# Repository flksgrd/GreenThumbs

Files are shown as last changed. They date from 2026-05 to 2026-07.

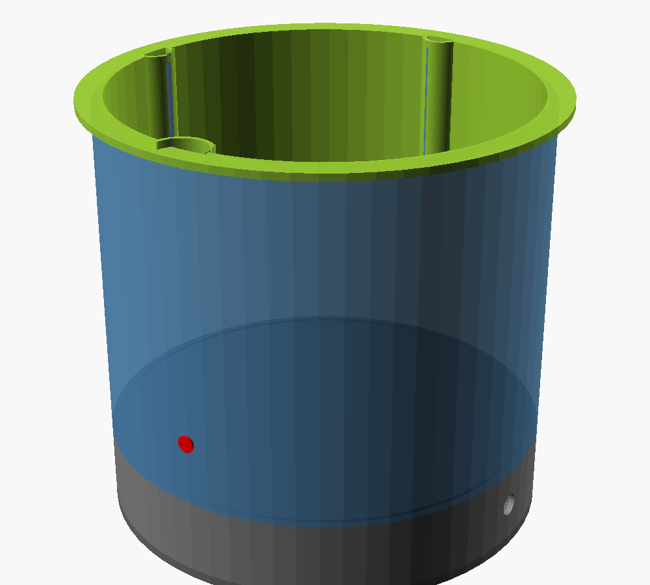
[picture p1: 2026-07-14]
pot/cad/preview/07-custom-monstera-iso.png

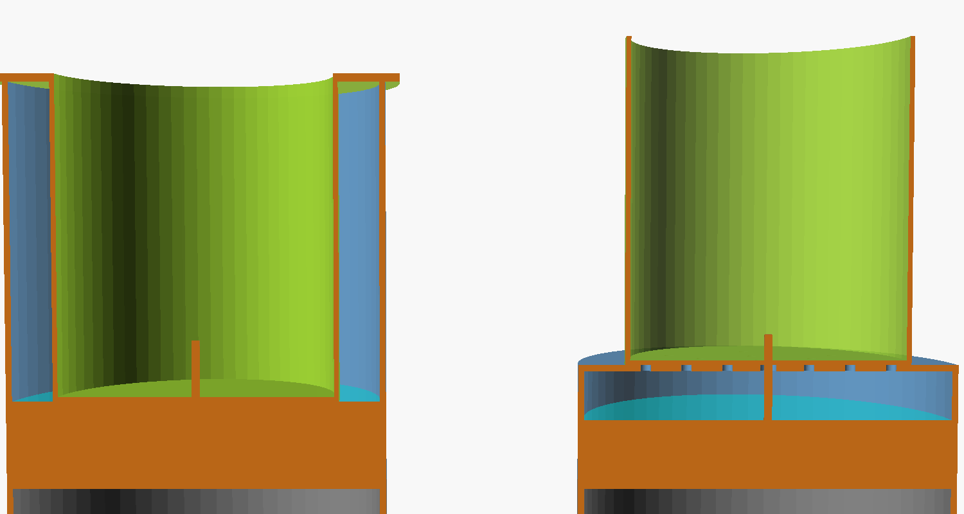
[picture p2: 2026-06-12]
pot/cad/preview/stack-variants-AB.png

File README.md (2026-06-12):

# 🌱 GreenThumbs

DIY auto-vandings-system til hjemmeplanter med Apple HomeKit-integration via Matter over Thread.

## Status

| Komponent | Status | Note |
|---|---|---|
| **v1: Smart Plantekrukke** | 🟡 Planlægning færdig, bygges nu | Modulær 3D-printet selvvandende krukke (med valgfri wick til bottom-watering) |
| **v2a: Pot-Orchid** | ⚪ Designfase only | Dedikeret orkide-krukke med soak-tray |
| **v2b: Vægmonteret Tower** | ⚪ Designfase only | Hydroponic til krydderurter/leafy greens |

## Oversigt

To designs til forskellige behov:

### 🪴 Smart Plantekrukke (v1 — denne iteration)

En modulær 3D-printet krukke der lever inde i en pyntepotte:

- **Plug-and-play planteprofiler**: Monstera, Pothos, Peace Lily, African Violet, Succulent, Orkide
- **Modulær sensor-stack**: kapacitiv jord-fugtighed + vandstand + float-switch + AHT20 (temp + RH) som basis. **Optional**: HX711 + 5kg load cell tilføjer vægt-detektion (krævet for orkide-bark; ikke nødvendigt for jord-planter)
- **VPD-aware vanding**: AHT20 measurer rum-klima og firmware skalerer dose dynamisk baseret på Vapor Pressure Deficit — mere vand i tør radiator-vinter, mindre i fugtigt klima
- **Bottom-watering option (v1 wick)**: bomulds-snor gennem center-drænhul → continuous capillary watering for African Violet, Peace Lily, Calathea og lignende fugt-elskere
- **Stille peristaltisk pumpe**: præcis dosering 5–100 ml, selv-primende, dry-run tolerant
- **Modulær størrelse**: skiftelig plantebeholder (S/M/L) — én reservoir + elektronik-base passer alle
- **Apple HomeKit** via Matter over Thread fra dag 1 (HomePod/Apple TV som Thread Border Router)
- **Strøm**: USB-C kablet i v1. Batteri-feasibility analyseret — realistisk i v2 med 3S 18650 + Sleepy End Device (~5-6 mdrs runtime)

→ Se [pot/](pot/) for byggeguide, hardware, firmware og CAD.

### 🪻 Pot-Orchid med Soak-Tray (v2a — kun planlægning)

Dedikeret orkide-krukke der mimicker manuel orkide-soaking: tray omkring plant cup oversvømmes via pump i 10-15 min, drænes derefter via solenoid eller passiv overflow tilbage til reservoir. Genbruger v1-elektronik 100%.

→ Se [pot-orchid/design-notes.md](pot-orchid/design-notes.md) for løbende planlægning.

### 🌿 Vægmonteret Hydroponic Tower (v2b — kun planlægning)

Vægophængt tower til krydderurter (basilikum, mynte, persille, koriander) og leafy greens (salat, spinat).
Deler MCU + firmware-platform med plantekrukken.

→ Se [tower/design-notes.md](tower/design-notes.md) for løbende planlægning.

## Quick reference

- **Komponentliste / BOM**: [pot/hardware/bom.csv](pot/hardware/bom.csv)
- **Wiring-diagram**: [pot/hardware/breadboard/wiring-diagram.md](pot/hardware/breadboard/wiring-diagram.md)
- **Planteprofiler**: [docs/plant-profiles.md](docs/plant-profiles.md)
- **Arkitektur**: [docs/architecture.md](docs/architecture.md)
- **Designbeslutninger (ADR)**: [docs/decisions/](docs/decisions/)
- **Research-noter**: [docs/research/](docs/research/) (KiCad rund PCB, piezo-komponenter)
- **Kalibrering**: [docs/calibration.md](docs/calibration.md)

## Tech stack

- **MCU**: Seeed Studio XIAO ESP32-C6 (Thread + WiFi + BLE + Matter)
- **Firmware**: PlatformIO + ESP-IDF + ESP-Matter SDK (C/C++)
- **CAD**: OpenSCAD (parametrisk, git-friendly)
- **3D print**: PETG til vand-kontakt dele, Prusa XL
- **Smart home**: Matter over Thread → Apple HomeKit

## Roadmap

- [x] Plan + arkitektur + BOM
- [ ] Bestil komponenter (AliExpress leadtime ~2-3 uger)
- [ ] Fase 1: Firmware bring-up på breadboard
- [ ] Fase 2: Mekanisk prototype i PLA → PETG
- [ ] Fase 3: Integration + 7-dages live-test
- [ ] Fase 4: Polish + assembly guide + OTA
- [ ] Fase 5: v2 tower-planlægning detaljeret

## License

MIT (software) — se [LICENSE](LICENSE). Hardware-design under overvejelse (CERN-OHL-S).

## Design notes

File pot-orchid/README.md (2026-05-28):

# 🪻 Pot-Orchid — Dedikeret orkide-krukke med soak-tray (v2)

**Status:** Designfase — bygges IKKE i denne iteration. Planlægges parallelt med v1 og vil bygge oven på lessons learned.

Dedikeret variant af plantekrukken designet specifikt til **orkider** (primært Phalaenopsis i bark-medium) og potentielt **store succulenter** der har gavn af ægte soak-watering.

## Hvorfor en separat krukke

Standard `pot/` v1 bruger top-drip via peristaltisk pumpe + drip-ring. Det virker godt for jord-baserede planter, men:

- **Orkide i bark**: bark-medium suger vand bedst ved nedsænkning (10-15 min soak), ikke drip. v1 approksimerer via 3×10s drip-bursts, men det er ikke ægte soaking.
- **Succulenter med tæt rosette** (Echeveria, Sempervivum, kaktus): top-drip kan ramme rosette-centrum → kronrådne. Bottom-watering via soak er sikrere.

Wick-løsningen i v1 dækker fugt-elskere (Peace Lily, African Violet, Calathea) men ikke orkide/succulent — disse vil have **tørre perioder** mellem soak-events, ikke konstant fugt.

→ Se [ADR 006](../docs/decisions/006-bottom-watering-strategies.md) for fuld kontekst.

## Quick reference (udfyldes løbende)

- [design-notes.md](design-notes.md) — løbende design-noter
- [references.md](references.md) — orkide-pleje litteratur, eksisterende designs
- preliminary-bom.md — kommer efter v1-validering

## Concept

```
┌──────────────────────────────┐
│  Lid med refill-tragt        │
├──────────────────────────────┤
│  INNER PLANT CUP             │  ← bark-medium, ikke jord
│   • Større drænhuller        │
│   • Soaker fra bunden via    │
│     tray-overflow            │
├──────────────────────────────┤
│  SOAK TRAY                   │  ← KEY DIFFERENCE
│   • Fyldes via pump (10-15min│
│     med vand op til soak-line│
│   • Drænes via solenoid eller│
│     passiv overflow tilbage  │
│     til reservoir            │
├──────────────────────────────┤
│  RESERVOIR                   │
├──────────────────────────────┤
│  ELECTRONICS BASE            │
│   • + solenoid driver         │
│   • + drain-control logik    │
└──────────────────────────────┘
```

## Forskelle fra pot/ v1

| Aspekt | pot/ v1 | pot-orchid/ v2 |
|---|---|---|
| Vandingsstrategi | Top-drip via drip-ring | Bottom-soak via tray |
| Pumpe-cyklus | Diskret dose 5-100ml | Fyld tray over 5-10 min |
| Drain-mekanisme | Ingen (cup-drænhuller → reservoir) | Solenoid eller passiv overflow |
| Medium | Jord | Bark (default) eller specialiseret kaktusjord |
| Soil-sensor | Capacitiv (relevant) | Måske irrelevant — vægt + tray-vandstand bruges |
| Tray-vandstand sensor | Ikke nødvendig | Ja (extra capacitive eller float) |
| Cup-design | Drænhuller spredt | Stort centralt drænhul + perimeter for tray-tilstrømning |

## Roadmap

- [ ] v1 (pot/) firmware + hardware fungerer end-to-end
- [ ] v1 wick-test: er bottom-watering tilstrækkeligt for fugt-elskere? Bekræfter behov for soak-tray til orkide/succulenter
- [ ] Udfyld design-notes med valg: solenoid-drain vs passiv overflow
- [ ] Beslut: udvider vi til 2 sizes (orkide small + stor succulent)?
- [ ] Skitse soak_tray.scad
- [ ] Foreløbig BOM (genbrug pot/-komponenter)
- [ ] Print + samling
- [ ] Live test med Phalaenopsis

## Genbrug fra pot/

| Komponent | Genbrug | Note |
|---|---|---|
| XIAO ESP32-C6 + ESP-Matter setup | 100% | Samme MCU + firmware base |
| Peristaltisk pumpe + MOSFET | 100% | Samme driver, anden brug (tray-fyld i stedet for drip) |
| HX711 + 5kg load cell | 100% | Vægt-baseret detektion er endnu vigtigere her |
| Float switch + interlock | 100% | Lavt vand i reservoir |
| ZY12PDN + MP1584 strøm | 100% | Samme |
| Plant profile struct | Udvides | Tilføj soak-tid + drain-tid felter |
| OpenSCAD shared moduler | 100% | M3 inserts, gaskets fra shared/cad-lib |

## Nye ting v2 kræver

- **Soak tray** (3D-printet, vandtæt) der omslutter plant cup
- **Solenoid-ventil** (12V, normalt-lukket) til drain — eller passiv overflow design
- **Tray water level sensor** (capacitive strip eller flydende sensor)
- **Firmware**: tilstands-maskine (FILL → SOAK → DRAIN → DRY) med konfigurérbare tider per plante

## License

Same as project root — MIT.

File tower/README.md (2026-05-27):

# 🌿 Vægmonteret Hydroponic Tower (v2)

**Status:** Designfase — bygges IKKE i denne iteration. Opdateres løbende mens vi lærer fra plantekrukke-prototypen (`pot/`).

Hydroponic vægmonteret tower til **krydderurter** (basilikum, mynte, persille, koriander) og **leafy greens** (salat, spinat, grønkål).

## Hvorfor først nu (efter pot)

Tower og pot deler:
- **MCU-platform**: XIAO ESP32-C6 + ESP-Matter SDK
- **Pumpe-driver-arkitektur**: MOSFET-style switching
- **Sensor-stack** (delvist): water level + float switch
- **Firmware-skelet**: FreeRTOS-task arkitektur, NVS-baseret config

Ved at bygge pot først, validerer vi al elektronik + firmware. Tower bliver så primært en **mekanisk + plumbing-udfordring** med velkendt elektronik.

## Quick reference

- [design-notes.md](design-notes.md) — **løbende design-noter** (opdateres mens vi lærer fra pot)
- [preliminary-bom.md](preliminary-bom.md) — foreløbig komponentliste
- [references.md](references.md) — inspirations-designs, links, papers

## Concept

```
┌─────────────────────────┐  ← Vægbeslag
│  Plant slot 1 (top)    │  ← Krydderurter i net cups
├─────────────────────────┤
│  Plant slot 2          │  ← Vand recirkuleres ned
├─────────────────────────┤
│  Plant slot 3          │
├─────────────────────────┤
│  Plant slot 4          │
├─────────────────────────┤
│  Plant slot 5 (bottom) │
├─────────────────────────┤
│  RESERVOIR + PUMP      │  ← Submersible aquarium pumpe
│  (synlig vandlinje)    │  ← Transparent "vindue"
│  + Water level sensor  │
└─────────────────────────┘
   ↑
   Strøm via stikkontakt / lampeudtag
```

## Forskelle fra pot

| Aspekt | Pot (v1) | Tower (v2) |
|---|---|---|
| Vandingsstrategi | Drip via peristaltisk | Continuous recirculation |
| Pumpe-type | Peristaltisk 12V | Submersible aquarium (5V eller 12V) |
| Medium | Jord | LECA/clay pebbles eller rockwool |
| Plante-detektion | Soil moisture + vægt | N/A (vand altid tilstede; tjek pH/EC) |
| Reservoir | 700-1500 ml | 2-4 L (mindre genopfyldnings-frekvens) |
| Strøm | USB-C kablet | AC stikkontakt (større pumpe) |
| Storage | Compact under pot | Hele bottom-segmentet |

## Roadmap

- [ ] v1 (pot) firmware fungerer ende-til-ende
- [ ] Udfyld design-notes.md med erfaringer fra pot-byg
- [ ] Beslut: NFT (Nutrient Film Technique) vs DWC (Deep Water Culture) vs vertical drip
- [ ] Skitse tower-design (5-7 plante-slots?)
- [ ] LED grow lights? (krydderurter klarer sig i vindueslys; salat behøver mere)
- [ ] pH + EC monitoring (basic eller skip i v2?)
- [ ] Foreløbig BOM
- [ ] OpenSCAD-design af tower-segmenter
- [ ] PETG-print + samling
- [ ] Live test med basilikum + mynte

## License

Same as project root — MIT.

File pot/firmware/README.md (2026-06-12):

# Plantekrukke Firmware

PlatformIO + ESP-IDF + ESP-Matter SDK projekt for XIAO ESP32-C6.

## Setup (første gang)

### 1. PlatformIO Core

```bash
pip install --break-system-packages platformio
```

Eller via VS Code / Antigravity: install "PlatformIO IDE" extension.

### 2. ESP-Matter SDK

ESP-Matter SDK kommer ikke automatisk med PlatformIO. Den skal klones manuelt:

```bash
# Fra et stabilt sted (ikke i dette repo)
cd ~/
git clone --recursive https://github.com/espressif/esp-matter.git
cd esp-matter
git checkout v1.3  # pin til specifik version, ikke main
./install.sh
```

Tilføj så til din shell profile (`~/.zshrc`):

```bash
export ESP_MATTER_PATH=$HOME/esp-matter
source $ESP_MATTER_PATH/export.sh
```

### 3. ESP-IDF (auto-installeres af PlatformIO)

PlatformIO installerer ESP-IDF 5.1+ automatisk når du første gang kører `pio run`.

## Build & flash

```bash
cd pot/firmware
pio run                    # build
pio run -t upload          # flash via USB-C
pio device monitor         # serial monitor (115200 baud)
```

## First-time Matter pairing

Efter flash, serial monitor printer en QR-kode + setup PIN:

```
Matter device ready.
QR Code:       MT:Y.K9042C00KA0648G00
Manual PIN:    20202021
Discriminator: 3840
```

I Apple Home-app:
1. "Tilføj tilbehør" → "Mere"
2. Scan QR-kode med iPhone-kamera (eller indtast PIN manuelt)
3. Følg setup-wizard

## Unit tests

```bash
pio test -e native_test    # kør native unit tests (ikke på ESP32)
pio test -e greenthumbs_pot  # kør on-target tests (kræver ESP32 tilsluttet)
```

## Folder struktur

```
firmware/
├── platformio.ini          # PlatformIO config
├── sdkconfig.defaults      # ESP-IDF default settings
├── partitions.csv          # Flash partition layout
├── src/
│   ├── main.cpp                # Entry + task spawning + pin assignments
│   ├── pump.cpp / .h           # Pump MOSFET drive + dosering (TODO Fase 1)
│   ├── sensors.cpp / .h        # Soil ADC + water level + float ISR (TODO Fase 1)
│   ├── weight.cpp / .h         # HX711 driver, optional hardware (TODO Fase 1)
│   ├── temp_humidity.cpp / .h  # AHT20 I2C + VPD calc — VPD math virker; I2C TODO
│   ├── profiles.cpp / .h       # Plant profile + NVS storage
│   ├── safety.cpp / .h         # Watchdog + leak detect (TODO Fase 1)
│   └── matter_iface.cpp / .h   # Matter cluster bindings (TODO Fase 1)
├── include/                # Public headers (hvis nogen)
├── lib/                    # Local libraries (genbrug fra shared/firmware-lib)
└── test/                   # Unit tests (native + on-target)
```

## Status

- [x] Repo skeleton + platformio.ini config
- [x] profiles.h struct + profiles.cpp (factory defaults + threshold/dose-logik)
- [x] temp_humidity.h API + VPD math implementation (I2C-driver TODO Fase 1)
- [x] buzzer.h/.cpp skeleton (refill-indikator, ADR 008)
- [x] USB-CDC console configuration (sdkconfig.defaults)
- [x] Audit-fixes: partitions.csv 4MB-layout, platform IDF 5.2+, task stacks
- [x] main.cpp task skeleton
- [ ] Implementér sensors.cpp (Fase 1)
- [ ] Implementér pump.cpp (Fase 1)
- [ ] Implementér weight.cpp (Fase 1)
- [ ] Implementér matter_iface.cpp (Fase 1)
- [ ] First-time Matter pairing test (Fase 1)
- [ ] Unit tests (Fase 1)
- [ ] OTA flow (Fase 4)

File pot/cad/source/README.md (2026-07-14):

# OpenSCAD CAD Source

Parametriske 3D-modeller for plantekrukken. Alle dimensioner styres fra `params.scad`.

## Workflow

**For at se og rendere geometri:** Åbn én af part-filerne (ikke `params.scad`).

| Fil | Hvad det renderer |
|---|---|
| [params.scad](params.scad) | Ingen geometri — kun variable + echo til console. Åbn for at *redigere* dimensioner. |
| [plant_cup.scad](plant_cup.scad) | Skifteligt indre kop (jord + plante). Størrelse styret via `cup_size`. |
| [reservoir.scad](reservoir.scad) | Vand-beholder med sensor-slots + pump-port + refill-notch. |
| [electronics_base.scad](electronics_base.scad) | Vandtæt elektronik-kammer + aftageligt låg (renderes side-by-side). Lid har **dual-footprint pump-mount**: Kamoer KPP (2× M3, 46mm c-c) eller Bartels BP7 piezo + driver (4× M3, 24mm kvadrat) — se [piezo-research](../../../docs/research/piezo-components.md). |
| [load_cell_mount.scad](load_cell_mount.scad) | Vægt-platform (lower plate + upper plate + load cell visualisering). |

## Skift plantestørrelse

1. Åbn `params.scad` i din editor (VS Code, Antigravity, eller OpenSCAD).
2. Ændr `cup_size = "M"` → `"S"` eller `"L"`.
3. Gem filen.
4. Åbn `plant_cup.scad` i OpenSCAD.
5. **F5** for preview, **F6** for full render, **File → Export → Export as STL**.

**Tip:** I OpenSCAD, aktivér `Design → Automatic Reload and Preview`. Så genindlæses `plant_cup.scad` automatisk når du ændrer `params.scad` i et andet program.

## Eksportér alle STL'er fra kommandolinje

```bash
cd pot/cad/source
OPENSCAD=/Applications/OpenSCAD-2021.01.app/Contents/MacOS/OpenSCAD

# Plant cups i alle 3 størrelser
for size in S M L; do
    $OPENSCAD -D "cup_size=\"$size\"" -o ../stl/plant-cup-$size.stl plant_cup.scad
done

# Reservoirs i begge volumer
for vol in 700 1500; do
    $OPENSCAD -D "reservoir_volume_ml=$vol" -o ../stl/reservoir-${vol}ml.stl reservoir.scad
done

# Electronics base + lid
$OPENSCAD -o ../stl/electronics-base.stl electronics_base.scad
# (Lid renderes sammen med base; manuel split for nu)

# Load cell mount
$OPENSCAD -o ../stl/load-cell-mount.stl load_cell_mount.scad
```

## Print-strategi

1. **Validér først i PLA** (billigt, hurtigt). Tjek dimensioner, snap-fits, hulplaceringer.
2. **Iterér** — typisk 2-3 print-runs før alle mål er rigtige.
3. **Endelig print i PETG** for vand-kontakt dele (plant_cup, reservoir, electronics_base).
4. **Load cell mount + lid** kan blive i PLA (ingen vand-kontakt).

## Wick installation (bottom-watering for African Violet, Peace Lily, Calathea)

For planter der foretrækker bottom-watering installeres en cotton/nylon-wick gennem center-drænhullet:

1. Tag ~15cm 4mm flettet bomulds- eller nylon-snor.
2. Inden plant cup fyldes med jord: træd snoren gennem center-drænhullet (det centrale 4mm hul i hex-mønstret).
3. Lad 6-8cm gå op i jord-zonen og 6-8cm hænge ned.
4. Læg lidt jord under wick'en så den holdes på plads.
5. Fyld resten af jorden om wick'en — kompakt let.
6. Når cup placeres i reservoir, skal den nedhængende ende dyppe i vandet.

Ingen CAD-ændring nødvendig — eksisterende 4mm center drænhul er rigeligt for 4mm snor. Se [ADR 006](../../../docs/decisions/006-bottom-watering-strategies.md) og [plant-profiles.md](../../../docs/plant-profiles.md) for hvilke profiler der bruger wick.

## Stack-geometri: Variant A + scalloped cup (ADR 010, 2026-07)

Cuppen hænger **nedsænket** i reservoiret fra sin flange og fylder næsten
hele åbningen (1mm kant-clearance). I stedet for et koncentrisk ring-gab
har cuppen **3 lodrette service-kanaler** — konkave udskæringer i kanten:

| Vinkel | Kanal | Ø | Funktion |
|---|---|---|---|
| 90° | Kabel | 16 | Soil/strip/float-kabler |
| 180° | Slange | 18 | Suge + tryk (dyse-hul i kanal-flade nær top) |
| 270° | Refill | 28 | Påfyldning + water-strip m. ribber |

Vandet lever i zonen under cup-bunden (op til overflow-niveau, ADR 009) —
kanalerne er TØRRE servicekanaler.

**Orientering:** strip-ribberne på reservoir-væggen (fuld højde, ved 270°)
passerer kun den brede refill-kanal → cuppen kan kun sænkes ned i ÉN
rotation. **Centrering:** kant-clearance. Ingen tapper/lommer.

**Adaptivt:** cup-størrelsen driver alle diametre (matchende sæt per
størrelse — reservoir/base re-printes ved størrelses-skift):

| cup_size | Cup | Ydre Ø | Kapacitet | Total højde | Pyntepotte (indre) |
|---|---|---|---|---|---|
| S | Ø100×120 | 108 | ~261 ml | ~208mm | ≥ Ø128 |
| M | Ø140×160 | 148 | ~507 ml | ~248mm | ≥ Ø168 |
| L | Ø180×200 | 188 | ~832 ml | ~288mm | ≥ Ø208 |
| CUSTOM (eksempel) | Ø230×145 | 238 | ~1353 ml | ~233mm | Ø260×230 (Monstera-potte) |

**CUSTOM**: sæt `custom_cup_diameter`/`custom_cup_height` i params.scad frit
efter din pyntepotte — echo-outputtet viser pyntepotte-kravet direkte.
**Mere kapacitet?** Øg `water_zone_h` (40 → 55mm giver +47% vand for +15mm
total højde).

Visualisér med [assembly_check.scad](assembly_check.scad) — view-modes:
`iso|section|top|exploded|reservoir|ebase` (se fil-header). Renders i
[../preview/](../preview/). [stack_variants_preview.scad](stack_variants_preview.scad)
er historisk beslutningsgrundlag (A vs B) og holdes ikke opdateret.

## v1 → v1.1 TODO

Ting der mangler men ikke blokerer for første prototype:

- [ ] Soil sensor mount: integreret holder på cup (eller separat clip-on del)
- [ ] Pump-slange grommet i electronics base top
- [ ] Refill funnel-design (separat top-del der klikker på reservoir)
- [ ] Drip ring på top af plant cup (jævn fordeling af vand)
- [ ] Snap-fit cable gland (alternativ til M12/PG7 metal glands)
- [ ] Hex-pattern dræn i bund (lige nu er det 1 center + 6 ring; hex giver bedre flow)
- [ ] Optional wick-guide tube under center drænhul (holder wick aligned + minimiserer sideways drag)

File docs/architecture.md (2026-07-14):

# Systemarkitektur — GreenThumbs Plantekrukke v1

## Overordnet billede

```
+-----------------------------------------------------------------+
|                    APPLE HOMEKIT (iPhone/iPad)                  |
+-----------------------------------------------------------------+
                              ↕
                  (Matter over Thread)
                              ↕
+-----------------------------------------------------------------+
|     HomePod mini / Apple TV 4K (Thread Border Router)           |
+-----------------------------------------------------------------+
                              ↕
                  (Thread mesh, 802.15.4)
                              ↕
+=================================================================+
|             SMART PLANTEKRUKKE — BASE STATION                   |
|                                                                 |
|   USB-C PD adapter (≥30W)                                       |
|        ↓                                                         |
|   ZY12PDN PD trigger (12V)                                      |
|        ├──→ MOSFET (IRLB8721) ──→ Peristaltisk pumpe 12V        |
|        └──→ MP1584 buck (12V→5V) ──→ XIAO ESP32-C6              |
|                                          │                       |
|                                          ├── ADC0: soil moisture │
|                                          ├── ADC1: water level   │
|                                          ├── GPIO ISR: float     │
|                                          ├── I2C: AHT20          │ (temp + RH)
|                                          ├── GPIO: HX711 SCK/DT  │ (optional)
|                                          ├── GPIO: status LED    │
|                                          ├── GPIO: manual btn    │
|                                          └── GPIO PWM: pump      │
+=================================================================+
```

## Fysisk stack (top → bund)

```
STACK VARIANT A (besluttet 2026-06): cup hænger NEDSÆNKET i reservoiret.

┌══════════[ FLANGE Ø202 ]══════════┐ ← universal-flange hviler på rim;
│  ↓ refill-åbning (270°)           │   refill-åbning + slange-hul i flangen
│ ┌───────────────────────┐         │
│ │  INNER PLANT CUP      │ ←ring-  │ ← skiftelig S(Ø100)/M(Ø140)/L(Ø160)
│ │   • jord              │  gap    │   hænger nedsænket i reservoiret
│ │   • soil sensor       │ (slange │
│ │   • drænhuller i bund │  + strip│ ← water level strip i ring-zonen
│ │   • wick gn. center   │  her)   │
│ └─────────┬─────────────┘         │
│   VAND-ZONE (40mm, ~1018 ml)      │ ← float switch i bund, under cup
╞═══════════════════════════════════╡
│  ELECTRONICS BASE (vandtæt)       │
│   • XIAO ESP32-C6 + AHT20 + buzzer│
│   • MOSFET + buck-converter       │
│   • Pumpe på lid (dual footprint: │
│     Kamoer KPP eller BP7 piezo)   │
│   • O-ring/EPDM gasket på top     │
├───────────────────────────────────┤
│  LOAD CELL platform (OPTIONAL)    │ ← kun for orkide / power-user
│   • HX711 ADC + bar load cell 5kg │
│   • Skip for store planter — brug │
│     rubber feet på lid i stedet   │
└───────────────────────────────────┘

SCALLOPED CUP (ADR 010, 2026-07): cuppen fylder næsten hele reservoir-
åbningen; 3 lodrette service-kanaler i cup-kanten (kabel Ø16 @ 90°,
slange Ø18 @ 180°, refill Ø28 @ 270°) erstatter ring-gabet. Cup-størrelsen
driver alle diametre — hver størrelse er et matchende sæt:

| Størrelse | Cup | Ydre Ø | Kapacitet | Total højde | Pyntepotte |
|---|---|---|---|---|---|
| S | Ø100×120 | 108 | ~261 ml | ~208mm | ≥ Ø128 |
| M | Ø140×160 | 148 | ~507 ml | ~248mm | ≥ Ø168 |
| L | Ø180×200 | 188 | ~832 ml | ~288mm | ≥ Ø208 |
| CUSTOM | frit | beregnes | beregnes | beregnes | tunes til potten |

(+ ~33mm højde med optional load cell.) Rotations-lås: reservoir-væggens
strip-ribber passerer kun refill-kanalen → kun én mulig orientering.
Centrering: 1mm kant-clearance.
```

## Vandstrøm (zero-penetration, ADR 009)

Reservoiret har INGEN gennemføringer under vandlinjen — begge slanger ruter
gennem ring-gabet og flangens 180°-åbning, og løber udvendigt ned til
electronics base's side-glands:

```
Reservoir vand-zone (under cup)
     │
     ↓ SUGESLANGE (m. sinker-vægt) op gennem ring-gab → flange-åbning 180°
       → ned UDVENDIGT → PG9-gland i ebase-siden → pumpe-indgang
     │
     ↓ Peristaltisk pumpe i electronics base (drevet via MOSFET, 12V)
     │
     ↓ TRYKSLANGE ud af PG9 → op UDVENDIGT → flange-åbning 180°
       → ind i cup-toppens side-hul → dripper på jord-overfladen
     │
     ↓ Jord → plantens rødder
     │
     ↓ Overskud drypper gennem cup-drænhuller → tilbage i vand-zonen
       (lille intern recirkulation; acceptabelt — jordmængden i dryppet
        er minimal, og wick-planter trækker alligevel direkte fra zonen)

OVERFYLDNING: vandstand > overflow-niveau (8mm under cup-bund)
     → overskud løber ud af overflow-hullet (270°, under refill-åbningen)
       ned i pyntepotten — synligt signal, planten drukner ALDRIG
```

**Wick-flow (ADR 006):** for bottom-watering planter hænger en bomulds-wick
fra cup'ens center-drænhul direkte ned i vand-zonen (20-50mm afstand) —
kontinuert kapillær-vanding uden pumpe.

**Sensor-kabler** (soil, water-strip, float): op gennem ring-gab → flangens
kabel-slids (90°) → ned udvendigt → PG7-gland i ebase-siden.

## Software-arkitektur

```
┌─────────────────────────────────────────────────────────┐
│                    main.cpp                             │
│   app_main() — init NVS, sensors, Matter, start tasks   │
└─────────────────────────────────────────────────────────┘
                            │
        ┌───────────────────┼─────────────────────┐
        ↓                   ↓                     ↓
┌─────────────┐    ┌──────────────┐    ┌──────────────┐
│ sensor_task │    │ control_task │    │ matter_task  │
│             │    │              │    │              │
│ Sample alle │←──→│ Eval profile │←──→│ Matter event │
│ sensorer    │    │ → pump?      │    │ loop +       │
│ hver 30s    │    │              │    │ clusters     │
└─────────────┘    └──────────────┘    └──────────────┘
        ↑                   ↑                     ↑
        └───────────────────┼─────────────────────┘
                            ↓
                   ┌────────────────┐
                   │  safety_task   │
                   │ Watchdog +     │
                   │ float ISR +    │
                   │ leak detect    │
                   └────────────────┘
```

**Shared state** mellem tasks via FreeRTOS mutexes:
- `sensor_state_t` (latest soil/water/weight readings)
- `plant_profile_t` (aktiv profil fra NVS)
- `pump_state_t` (last_pump_time, cumulative_ml_today)

**Communication mellem ESP32 og HomeKit:**

| Software-koncept | Matter cluster | HomeKit-visning |
|---|---|---|
| Soil moisture % | Humidity Sensor (endpoint 1) | "Jord-fugtighed: 42%" |
| Water reservoir % | Humidity Sensor (endpoint 2) | "Vandstand: 78%" |
| Float low (binær) | Leak Detector | "Vandalarm: OK" / "Tom" |
| Manuel pump | On/Off Switch | Knap der auto-slukker efter 3 sek |
| Profile-vælger | Mode Select | Dropdown: Monstera / Pothos / Peace Lily / African Violet / Succulent / Orkide / Custom |
| Rumtemperatur (AHT20) | Temperature Sensor (endpoint 3) | "Stuetemperatur: 22.4°C" |
| Luftfugtighed (AHT20) | Humidity Sensor (endpoint 3) | "Luftfugtighed: 47%" |
| Weight (gram, hvis HX711 tilstede) | Custom cluster (v2) | "Plante-vægt: 1248g" |

**VPD-aware dose-modifikator:** Når AHT20 er tilstede, justerer firmware automatisk `dose_ml` baseret på Vapor Pressure Deficit (rum-tørhed × temperatur). Ved tørt indeklima (vinter med radiator) får planten mere vand per cyklus; ved fugtigt klima reduceres dosen. Se [ADR 007](decisions/007-env-sensor-aht20.md).

## Load cell-placering: bivirkninger

Load cell sidder i bunden af stakken — under electronics base — af tre årsager:

1. **Vandslangen krydser ingen flex-joint.** Pump-output går fra reservoir gennem electronics base op til plant cup. Hvis cellen lå mellem reservoir og cup (eller mellem electronics base og reservoir), ville den stive silikoneslange spænde over flex-jointen og påføre en uforudsigelig kraft (~50g, hvilket drukner vores 10-100g signal for orkide).
2. **HX711-wiring er kortest.** ADC-modulet sidder i electronics base. Cell-til-ADC kablet behøver kun krydse ét vandtæt grommet — direkte ned i electronics base bund.
3. **Mekanisk stabilitet.** Rigid stak ovenpå én flex-joint er stabil. Flex-joint midt i stakken giver vippe-risiko, især med tunge planter.

Dette giver to bivirkninger der skal kompenseres i firmware/build:

### Pumpe-vibrationer påvirker måling

Pumpen sidder i electronics base, direkte over load cell platformen. Vibrationer fra pumpe-drift forplanter sig ned i cellen.

**Mitigation:**
- Firmware bruger 5-sample moving average på HX711-readings.
- **Sample ALDRIG mens pumpen kører.** Tilføj `if (pump_active) skip_weight_sample;` i sensor_task.
- Vent minimum 30 sek efter pump stop før første nye weight sample (mekaniske oscillationer dør ud).

### Termisk drift fra elektronik

ESP32-C6 + MP1584 buck-converter genererer ~1-2W varme. Varmen vandrer gennem electronics base bund → ind i load_cell_mount upper plate → påvirker HX711-aflæsning (~50 ppm/°C drift = ~0.5g per grad ved 5kg fuldskala — ikke meget, men akkumuleres over et døgn med vekslende rumtemp).

**Mitigation:**
- Læg en 2-3mm rubber-pad mellem electronics_base_lid og load_cell_mount upper plate som termisk isolation.
- Re-tare via HomeKit-knap ved sæson-skifte eller tydelig drift.
- Sample baseline-vægt om natten (lavest temperatur-gradient) hvis høj præcision er kritisk.

## Sikkerheds-architecture

Multi-layer defense mod uheld:

1. **Hardware**: Float switch i reservoir-bund. Hvis vand tomt → ISR sætter `pump_disabled_hw = true`. Software kan ikke override.
2. **Firmware**: Watchdog task tjekker at sensor-data ikke er stuck. Hvis stuck > 5 min → reboot.
3. **Logic**: Cooldown mellem doseringer (min `cooldown_min` per profil). Forhindrer over-watering.
4. **Daglig cap**: Max `daily_ml_cap` per profil. Forhindrer runaway-vanding.
5. **Manuel override**: knap på krukken + HomeKit-switch til at trig en pump-cyklus (med safety-checks).
6. **Leak detection**: hvis vægt falder hurtigere end forventet → mistænkt lækage → disable pump + alert.

## Repo-navigation

- [pot/](../pot/) — alt v1 (firmware, hardware, CAD)
- [tower/](../tower/) — v2 planlægning (kun docs)
- [shared/](../shared/) — genbrugbar kode/CAD mellem v1 og v2
- [docs/decisions/](decisions/) — ADR'er der dokumenterer hvorfor
- [docs/plant-profiles.md](plant-profiles.md) — profil-bibliotek
- [docs/calibration.md](calibration.md) — kalibreringsprocedure

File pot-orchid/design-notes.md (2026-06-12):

# Pot-Orchid Design Notes

**Status:** Initielle design-noter. Opdateres løbende mens v1 (`pot/`) bygges.

Dette dokument samler designvalg, åbne spørgsmål, og lessons learned der akkumuleres under v1-arbejdet. Når v1 er færdig, vil dette være grundlag for v2 pot-orchid-implementering.

---

## Brugerkrav

- **Ægte soaking**: tray oversvømmes med vand op til "soak-line" → står i 10-15 min → drænes
- **Stille drift**: pumpen kører kun under fyld/drain (~30-60 sek total per uge ved Phalaenopsis-cyklus)
- **Bark-medium**: bark, ikke jord. Større drænhuller for at vandet kan trænge ind/ud
- **Vægt-detektion påkrævet**: bark-medium gør capacitive soil sensor upålidelig (samme problem som beskrevet i ADR 004)
- **Genbrug v1-elektronik**: samme MCU, pumpe, sensorer, kun ekstra solenoid + tray water level sensor

---

## Designvalg (foreløbige)

### Pumpe-valg: piezo-option (fra piezo-research 2026-06)

Bartels BP7 piezo-mikropumpe (€57 + mp-Lowdriver €67 ≈ 925 DKK) blev fravalgt i pot/ v1 (6× pris, ingen reel energigevinst). **Men til pot-orchid er den interessant:**
- Soak-tray fyldes langsomt → BP7's lave flow (0-9 ml/min) er ikke en ulempe her
- Nær-lydløs drift passer soveværelses-placering
- Præcis dosering ned til µl-niveau
- pot/ electronics_base får dual-footprint pump-mount, så BP7 kan testes dér først

→ Se [docs/research/piezo-components.md](../docs/research/piezo-components.md). Status: premium-option, beslut efter v1-validering.

### Drain-mekanisme: solenoid vs passiv overflow

**Foreløbig beslutning:** Passiv overflow (enklere, ingen ekstra elektronik).

**Solenoid-drain:**
- Pro: præcis kontrol over hvornår tray drænes
- Pro: kan holde tray fyldt for lange soak-cykler (>1 time hvis ønsket)
- Con: ekstra 12V solenoid (~150 DKK), driver kredsløb, vandtæt mounting
- Con: hvis solenoid fejler i lukket position → tray oversvømmer

**Passiv overflow:**
- Tray har en overflow-hul i siden ved "soak-line"-højde. Vand der pumpes ind over denne højde løber tilbage til reservoir via overflow-rør.
- Soak-tid styres af pump-aktiverings-tid: pump fylder tray → fortsætter til overflow → soak-tid løber → pump stopper → vand i tray VEDBLIVER indtil det fordamper / planten absorberer det
- Pro: ingen ekstra elektronik
- Con: ingen aktiv drain — vandet i tray skal absorberes/fordampe, kan tage timer
- Con: hvis pumpen ikke stopper rettidigt → kun overflow forhindrer overflow til gulv

**Status:** Lean toward passiv overflow for simplicity. Beslut endeligt efter v1-test af pumpe-præcision.

### Soak-cyklus tid

Standard Phalaenopsis soak:
- Soak-tid: 10-15 min
- Frekvens: 1 gang per uge (7 dage)
- Vandtemperatur: rumtemperatur (ikke koldt)

Firmware-tilstandsmaskine:

```
IDLE → (weight drop trigger) → FILLING → SOAKING → DRAINING → DRYING → IDLE
       ~7 dage cooldown        ~30 sek    ~12 min   ~5 min      ~1 dag
```

### Tray-størrelse

Hvilken tray-størrelse passer til en standard orkide?

Phalaenopsis i 12cm orkide-potte: typisk 100-150ml vand til soak.

Tray dimensioner (foreløbige):
- Indvendig diameter: 140mm (passer 12cm pot med spillerum)
- Højde: 50mm (med soak-line ved 40mm = ~600ml volumen)

Genbrug `params.scad` parametre hvor muligt; tilføj `tray_diameter`, `tray_height`, `soak_line_height`.

### Tray water level sensor

Behøver vi den? Argumenter:
- Pro: detekter om soak-cyklus rent faktisk når soak-line (sanity check på pumpe)
- Pro: detekter om drain fungerer (water level falder over tid)
- Con: endnu en sensor + wire-rute + kalibrering

Foreløbigt: ja, tilføj. Reuse capacitive water level strip type som i reservoir.

---

## Åbne spørgsmål (besvares løbende)

- [ ] Skal pot-orchid være ét stort print eller modulært (stack ovenpå pot/-base)?
- [ ] Solenoid eller passiv overflow? (lean: passiv)
- [ ] Hvordan ser bark-medium ud i en CAD-visualisering? (For at vælge drænhulsstørrelse)
- [ ] Skal vi støtte mock-orkide profiler for store succulenter også, eller kun orkide?
- [ ] Hvor sidder solenoiden hvis vi vælger den? (Inde i electronics_base eller ekstern?)
- [ ] Skal tray være transparent/halv-transparent så bruger kan se soak-progress?
- [ ] Hvor placeres tray water-level sensor? (Indvendigt slot eller eksternt monteret?)

---

## Lessons learned fra pot/ (opdateres løbende)

*Endnu intet — pot/ er ikke bygget.*

Pladsholder-sektioner der opdateres efter hver pot/-fase:

### Fra Fase 1 (firmware bring-up)
*TBD*

### Fra Fase 2 (mekanisk prototype)
*TBD*

### Fra Fase 3 (integration + live test)
*TBD*

### Specifikt relevant for pot-orchid
- Hvor præcis er peristaltisk pumpe efter kalibrering? (kritisk for tray-fyld uden overflow)
- Hvor godt detekterer load cell små vægt-fald i bark? (kalibrering reference)
- Termisk drift fra elektronik (hvor meget påvirker det vægt-måling over en uge)?

---

## Genbrug fra pot/

Se også [README.md](README.md) genbrugstabel.

Direkte genbrug af CAD-moduler fra `shared/cad-lib/`:
- M3 heat-set insert mount
- Gasket groove (for tray-til-reservoir seal)
- Cable gland holes

Genbrug fra `pot/cad/source/`:
- `reservoir.scad` mostly same
- `electronics_base.scad` udvides med ekstra cable gland for solenoid (hvis valgt)
- `load_cell_mount.scad` 100% genbrug
- `plant_cup.scad` udvides → `orchid_cup.scad` med færre, større drænhuller
- NY: `soak_tray.scad`

Genbrug fra `pot/firmware/`:
- Hele FreeRTOS task-skeletten
- profiles.h struct (udvides med soak-felter)
- HX711 driver
- Float switch ISR
- Matter cluster bindings

Ny firmware:
- `soak_cycle.cpp` — tilstands-maskine for FILL/SOAK/DRAIN/DRY
- Eventuelt `solenoid.cpp` hvis vi vælger solenoid-drain

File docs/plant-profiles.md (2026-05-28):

# Planteprofiler

Hver profil definerer vandstrategi for en bestemt plantetype. Profilerne er kompilerede ind som factory-defaults i firmware (`profiles.h`) og kan tweakes per-krukke via HomeKit Mode Select cluster.

## Hardware-konfiguration

Krukken kan bygges i to varianter afhængigt af hvilke planter du vil have:

| Variant | Hardware | Profiler der virker | Typisk brug |
|---|---|---|---|
| **Standard** (uden load cell) | Soil moisture + water level + float | `monstera`, `pothos`, `peace_lily`, `succulent`, `african_violet` | Alle jord-baserede planter |
| **Med vægt** (HX711 + 5kg load cell + load_cell_mount print) | + HX711 | Alle ovenstående + `orchid_phalaenopsis` | Tilføjer orkide-support |

→ Se [ADR 004](decisions/004-weight-based-orchid.md) for vægt-baseret detektion. → Se [ADR 006](decisions/006-bottom-watering-strategies.md) for wick (bottom-watering). → Se [ADR 007](decisions/007-env-sensor-aht20.md) for AHT20 environmental sensor og VPD-aware dose-justering.

## VPD-aware dose-modifikator

Med AHT20 (standard v1-komponent) skalerer firmware automatisk `dose_ml` baseret på Vapor Pressure Deficit:

```
actual_dose_ml = profile.dose_ml × clamp(VPD / 1.3, 0.5, 2.0)
```

Eksempler:
- 22°C / 50% RH → VPD ≈ 1.3 kPa → scale = 1.0 → uændret dose
- 28°C / 30% RH (vinter radiator-tør) → VPD ≈ 2.5 kPa → scale = 1.9 → næsten dobbelt dose
- 20°C / 70% RH (kølig fugtig) → VPD ≈ 0.7 kPa → scale = 0.54 → halv dose

Det betyder profil-værdierne nedenfor er **reference-doser ved komfort-klima**. I praksis tilpasser systemet sig automatisk til dit faktiske rum-klima uden manuel justering.

## Vandings-præferencer per plantetype

Ikke alle planter trives med top-vanding. Den følgende tabel summerer hvordan vores design håndterer hver kategori:

| Kategori | Eksempler | Ideal vanding | v1-løsning |
|---|---|---|---|
| **Top-vanding fungerer fint** | Monstera, Pothos, Philodendron, Peace Lily, Spider plant, Ficus, ZZ, Calathea | Top-drip eller bottom | ✅ Top-drip (drip-ring) |
| **Stærk præference for bottom** (top-vanding skader) | African Violet, Gloxinia, Begonia Rex, Cyclamen, Streptocarpus | Bottom only | ✅ **Tilføj wick** + sæt `dose_ml = 0` (rent bottom) |
| **Foretrækker bottom, tolererer top** | Pilea peperomioides, Snake plant (Sansevieria), Calathea | Bottom > top | ✅ Top-drip OK, eller wick for konstant fugt |
| **Soak-vanding** (nedsænkning 10-15 min) | Orkide (Phalaenopsis), kaktus, Echeveria, Sempervivum, Haworthia, Air plants (Tillandsia) | Bottom soak, tørre perioder | ⚠️ v1 approksimerer via drip-bursts; ægte soak kommer i [pot-orchid/](../pot-orchid/) v2 |

## Wick-metoden (v1 bottom-watering)

For planter der stærkt foretrækker bottom-watering: træd en 4mm flettet bomulds- eller nylon-snor (10-15cm) gennem plant cup's center-drænhul. 5-7cm i jorden, 5-7cm hænger ned i reservoir-vandet. Capillær virkning trækker vand op til jorden 24/7 — ingen pumpe-aktion nødvendig.

For ren bottom-watering: sæt `dose_ml = 0` så pumpen ikke samtidigt drypper ovenfra. For hybrid (wick + supplerende drip): hæv `target_min_pct` +5-10 punkter (jord er konstant fugtigere med wick) og hæv `cooldown_min`.

→ Se [ADR 006](decisions/006-bottom-watering-strategies.md) for installation og rationale.

## Detection modes

```c
typedef enum {
    DETECT_MOISTURE = 0,  // soil sensor → primær signal (alle jord-planter)
    DETECT_WEIGHT,        // HX711 load cell → primær signal (orkide kun)
    DETECT_HYBRID,        // moisture + weight som sanity check (advanced, custom)
} detection_mode_t;
```

## Profil-struct

```c
typedef struct {
    char name[16];
    detection_mode_t mode;

    // Soil moisture (DETECT_MOISTURE, DETECT_HYBRID)
    uint16_t adc_dry;            // sensor i luft
    uint16_t adc_wet;            // sensor i vand
    uint8_t target_min_pct;      // pump trigger threshold
    uint8_t target_max_pct;      // pump stop threshold

    // Weight (DETECT_WEIGHT, DETECT_HYBRID)
    int32_t weight_baseline_g;   // tara-vægt sat ved init
    int32_t weight_dry_delta_g;  // gram tabt før vanding (negativt tal)

    // Pump-styring (alle modes)
    uint16_t dose_ml;            // ml per cyklus
    uint16_t cooldown_min;       // min minutter mellem doseringer
    uint16_t daily_ml_cap;       // max ml per døgn (safety)

    // Orkide soak-cyklus (kun DETECT_WEIGHT)
    uint16_t soak_seconds;       // pump i X sek per soak-burst
    uint8_t soak_repeats;        // antal bursts per cyklus
    uint16_t soak_pause_seconds; // pause mellem bursts
} plant_profile_t;
```

## Predefinerede profiler

### `monstera`

Tropisk, jord-baseret. Foretrækker fugtig men ikke våd jord. Vejer typisk 3-10+ kg som voksen — **kører ikke på load cell**, bruger kun moisture sensor.

| Parameter | Værdi |
|---|---|
| `mode` | `DETECT_MOISTURE` |
| `target_min_pct` | 35% |
| `target_max_pct` | 55% |
| `dose_ml` | 50 |
| `cooldown_min` | 360 (6h) |
| `daily_ml_cap` | 100 |
| Hardware krav | Soil moisture sensor |
| Vandings-metode | Top-drip ✅ (wick ikke nødvendigt) |

### `pothos`

Tropisk, jord-baseret. Mere tørke-tolerant end Monstera.

| Parameter | Værdi |
|---|---|
| `mode` | `DETECT_MOISTURE` |
| `target_min_pct` | 30% |
| `target_max_pct` | 50% |
| `dose_ml` | 30 |
| `cooldown_min` | 720 (12h) |
| `daily_ml_cap` | 60 |
| Hardware krav | Soil moisture sensor |
| Vandings-metode | Top-drip ✅ (wick ikke nødvendigt) |

### `peace_lily`

Tropisk, jord-baseret. Sensitiv overfor under-vanding (hænger ved tørke).

| Parameter | Værdi |
|---|---|
| `mode` | `DETECT_MOISTURE` |
| `target_min_pct` | 40% |
| `target_max_pct` | 60% |
| `dose_ml` | 40 |
| `cooldown_min` | 480 (8h) |
| `daily_ml_cap` | 100 |
| Hardware krav | Soil moisture sensor |
| Vandings-metode | Top-drip OK, **wick anbefales** (Peace Lily elsker konstant fugt) |

> **Med wick:** hæv `target_min_pct` til 50%, `cooldown_min` til 1440 (24h). Pumpen supplerer kun ved akut tørke.

### `african_violet`

Saintpaulia, Gloxinia, Begonia Rex, Streptocarpus. Fuzzy-bladede planter der **IKKE må top-vandes** (vand på blade → svampepletter + rådning).

| Parameter | Værdi |
|---|---|
| `mode` | `DETECT_MOISTURE` |
| `target_min_pct` | 35% |
| `target_max_pct` | 50% |
| `dose_ml` | **0** (rent bottom-watering via wick) |
| `cooldown_min` | n/a (pumpe aldrig aktiv) |
| `daily_ml_cap` | 0 |
| Hardware krav | Soil moisture sensor + **wick påkrævet** |
| Vandings-metode | **Wick (bottom only)** — ingen top-drip |

> **Wick-installation kritisk:** denne profil sætter `dose_ml = 0` så pumpen aldrig aktiveres. Vandet kommer KUN via wick'en fra reservoir. Soil moisture sensor overvåger og advarer hvis wick ikke leverer nok (sjælden — wick + reservoir-vand er meget pålideligt).

### `succulent`

Crassula, Aloe Vera, Echeveria. Meget lidt vand. Moisture sensor virker fint i kaktus-jord.

| Parameter | Værdi |
|---|---|
| `mode` | `DETECT_MOISTURE` |
| `target_min_pct` | 10% |
| `target_max_pct` | 20% |
| `dose_ml` | 15 |
| `cooldown_min` | 4320 (72h = 3 dage) |
| `daily_ml_cap` | 15 |
| Hardware krav | Soil moisture sensor |
| Vandings-metode | Top-drip i jord-zonen ✅. **WICK FRARÅDES** — succulenter behøver tørre perioder mellem vandinger |

> **VIGTIGT:** Brug IKKE wick med denne profil. Succulenter rådner ved konstant fugt. Top-drip er fint fordi dose er lille (15ml) og rammer jord, ikke rosette.
> **Advanced:** Hvis du har load cell installeret, kan du bruge `custom` profil med `mode = DETECT_HYBRID` og `weight_dry_delta_g = -50` for ekstra safety.
> **Bedre løsning for tæt rosette (Echeveria, Sempervivum, kaktus):** vent på pot-orchid v2 med ægte soak-tray. Indtil da: top-drip er kompromis-løsning.

### `orchid_phalaenopsis`

Bark-medium, soaking-vanding. **Kræver load cell** — soil moisture sensor er upålidelig i bark.

| Parameter | Værdi |
|---|---|
| `mode` | `DETECT_WEIGHT` |
| `weight_dry_delta_g` | -80g (relativ til baseline) |
| `soak_seconds` | 10 |
| `soak_repeats` | 3 |
| `soak_pause_seconds` | 30 |
| `cooldown_min` | 10080 (7 dage) |
| `daily_ml_cap` | 100 |
| Hardware krav | **HX711 + 5kg load cell + load_cell_mount platform** |
| Vandings-metode | v1: top-drip i 3 bursts (approksimation). **Ægte soak-vanding kommer i [pot-orchid/](../pot-orchid/) v2** |

Soak-flow: når vægt-fald > 80g triggers, pump i 10s → pause 30s → pump i 10s → pause 30s → pump i 10s → cooldown 7 dage.

> **v1 begrænsning:** dette er ikke ægte orkide-soaking (nedsænkning af hele potten i vand 10-15 min). Bark suger mindre via drip end ved fuld nedsænkning. Acceptabelt for v1, men forventede resultater er suboptimale. Se [ADR 006](decisions/006-bottom-watering-strategies.md).
> **Hvis hardware mangler:** firmware detekterer at HX711 ikke svarer → status-LED gul → HomeKit Mode Select rapporterer fejl → pumpe disables. Skift til en `DETECT_MOISTURE`-profil eller installer load cell.

### `custom`

Alle felter brugerredigerbare via HomeKit. Default sættes til konservative værdier.

| Parameter | Default |
|---|---|
| `mode` | `DETECT_MOISTURE` |
| `target_min_pct` | 25% |
| `target_max_pct` | 45% |
| `dose_ml` | 25 |
| `cooldown_min` | 720 |
| `daily_ml_cap` | 50 |
| Hardware krav | Afhænger af valgt mode |

## Vælg din plante

Find din plantes generelle kategori og brug den nærmeste profil:

| Din plante er… | Brug profil | Wick? |
|---|---|---|
| Stor jord-baseret tropisk (Monstera, Strelitzia, Ficus) | `monstera` | Nej |
| Mellem jord-baseret tropisk (Pothos, Philodendron, ZZ) | `pothos` | Nej |
| Calathea (kan lide konstant fugt) | `peace_lily` | Optional (anbefales) |
| Sensitiv tropisk der hænger ved tørke (Peace Lily, Spathiphyllum) | `peace_lily` | Anbefales |
| Fuzzy-bladet (African Violet, Gloxinia, Begonia Rex, Streptocarpus) | `african_violet` | **Påkrævet** |
| Succulent / kaktus / Aloe | `succulent` | **Frarådes** |
| Orkide i bark-medium (Phalaenopsis) | `orchid_phalaenopsis` | Nej (vent på pot-orchid v2) |
| Andet / kender ikke krav | `custom` (start konservativt, juster) | Afhænger |

## Tilføj din egen plante

1. Mål en standard-vanding for planten manuelt (vej hvor meget vand du normalt giver).
2. Sæt `dose_ml` til ~1/3 af det (auto-vand giver mindre, oftere).
3. Brug `peace_lily`/`monstera` som startpunkt for tropiske, `succulent` for kaktus-familien.
4. Observer i HomeKit-app i 1-2 uger; juster `target_min_pct` op hvis planten ser tør ud, eller `cooldown_min` op hvis jorden er for våd.

## Kalibreringsnoter

- **Soil sensor `adc_dry` / `adc_wet`**: kalibreres per sensor-eksemplar (ikke per plante). Se [calibration.md](calibration.md).
- **Weight baseline** (kun DETECT_WEIGHT/HYBRID): sættes per krukke + plante via HomeKit "Tare"-knap når planten er nyligt vandet.
- Profiler er **udgangspunkter, ikke fakta**. Observer din specifikke plante og juster.

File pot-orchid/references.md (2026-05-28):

# Pot-Orchid — References & Inspiration

Links til orkide-pleje, hydroponic-soaking designs, og relaterede projekter. Tilføjes løbende under research.

## Orkide-pleje grundlag

- [American Orchid Society](https://www.aos.org/) — autoritativ kilde til Phalaenopsis-pleje
- Søg: "Phalaenopsis watering schedule", "orchid bark medium", "orchid soaking technique"

## Bark-mediums karakteristik

- Bark-størrelse vs vandretentions-tid
- Hvordan bark "ældes" (3-12 måneder) og hvornår det skal udskiftes
- Kontaktflade for vand-absorption

## Soak-tray / sub-irrigation designs

*Tilføj links efterhånden som du finder dem.*

- Søg Printables / Thingiverse: "orchid pot self-watering", "bottom watering pot"
- Kommercielle eksempler: Lechuza-line (sub-irrigation), Click and Grow

## Solenoid-ventiler 12V (hvis vi vælger den path)

- Generisk 12V solenoid ~150 DKK fra AliExpress / Conrad
- Normalt-lukket (NC) anbefales af safety-grunde
- Krav: kompatibel med drikke-vand (rustfri eller plastic interior)

## Smart home + soak-cyklus

- Matter cluster ideer: "Mode Select" for soak-state visning (IDLE / FILLING / SOAKING / DRAINING / DRYING)
- "Switch" cluster for manuel soak-trigger

## Tilføj løbende

Format:

```
- [Project Name](url) — kort beskrivelse
  - Pro: ...
  - Skip: ...
```

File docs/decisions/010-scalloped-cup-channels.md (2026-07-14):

# ADR 010 — Scalloped cup med service-kanaler (erstatter ring-gab)

**Status:** Accepted
**Dato:** 2026-07-14
**Erstatter delvist:** ADR 009's ring-gab-rutering (zero-penetration princippet består uændret)

## Context

Efter det adaptive diameter-redesign (fast ring_gap = 20mm) påpegede brugeren
at det koncentriske ring-gab er spild: i M-størrelsen ofres ~40% af det indre
tværsnit (10.053 mm² ring mod 15.394 mm² cup) til hvad der overvejende er tom
luft — kun tre smalle zoner bruges reelt (slanger, kabler, refill/strip).
Planten er ligeglad med om dens jord er perfekt cirkulær.

Brugerens forslag: gør cuppen ikke-cirkulær med lodrette kanaler til hver
funktion, og lad kanalernes asymmetri sikre korrekt orientering.

## Decision

**Cuppen fylder næsten hele reservoir-åbningen (1mm kant-clearance) og har
3 lodrette SERVICE-KANALER — konkave cirkel-udskæringer i kanten, centreret
på cup-omkredsen, med hver sin funktion og bevidst forskellige størrelser:**

| Vinkel | Kanal | Ø | Indhold |
|---|---|---|---|
| 90° | Kabel-kanal | 16 | Soil/strip/float-kabler (op til flangen, ned udvendigt til PG7-gland) |
| 180° | Slange-kanal | 18 | Suge- + trykslange (Ø6); trykslangens dyse-hul sidder i kanal-fladen nær cup-toppen |
| 270° | Refill-kanal | 28 | Påfyldning (vandkande-tud) + water-strip med guide-ribber på reservoir-væggen |

Kanalerne fortsætter op gennem flangen (klippet til reservoir-åbningen så
påfyldt vand kun kan lande i reservoiret). Implementeret som 2D-profil
(`circle - kanaler`) ekstruderet; hulrummet er samme profil offset
`cup_wall` indad — vægtykkelsen følger dermed kanal-konturen.

### Orientering og centrering — gratis

- **Rotations-lås:** water-strip-ribberne på reservoir-indervæggen (ved
  270°, nu i FULD højde) spænder ~26mm — de kan kun passere gennem
  refill-kanalen (Ø28). Kabel- (16) og slange-kanalen (18) er for smalle.
  Cuppen kan derfor fysisk kun sænkes ned i ÉN rotation.
- **Centrering:** 1mm kant-clearance — cuppen kan maksimalt forskydes 2mm.
- Rim-tapperne + flange-lommerne fra forrige iteration er FJERNET
  (overflødige).

## Consequences

### Positive

- **Maksimalt jordvolumen:** kanalerne koster ~700-900 mm² mod ring-gabets
  ~10.000 mm². Brugerens Monstera-potte (indre Ø260): cup vokser fra Ø190
  til Ø230 = +46% jord-areal.
- **Mindre fodaftryk for samme plante:** M-sæt er nu ydre Ø148 (var Ø186).
- **Orientering + centrering uden ekstra features** (tapper/lommer droppet).
- **Zero-penetration består:** kanalerne er stadig tørre servicekanaler over
  vandlinjen; reservoiret er stadig uden gennemføringer.
- Matcher brugerens skitse 1:1.

### Negative

- **Kapacitet per cup-størrelse falder** (reservoir-fodaftryk følger nu
  cuppen): S ~261 ml, M ~507 ml, L ~832 ml, CUSTOM-eksempel ~1353 ml.
  Kompenseres ved at vælge cuppen så stor som pyntepotten tillader (hele
  pointen), eller ved at øge `water_zone_h` (40 → fx 55mm giver +47%
  kapacitet for +15mm højde).
- **Refill-åbningen er mindre** end vandkande-venlige Ø18+ i gamle design?
  Nej — refill-kanalen er Ø28, større end før. OK.
- Cup-print er marginalt mere komplekst (konkave flader) — men lodrette
  vægge, ingen support.
- Strip-ribber i fuld højde bruger lidt mere filament.

### Alternativer overvejet

- **Koncentrisk ring-gab (forrige design):** forkastet — 40% arealspild.
- **Kanaler som lukkede rør i cup-væggen:** tættere, men kabler med stik
  kan ikke trækkes igennem, og print kræver support i lukkede kanaler.
  Åbne konkave kanaler er tilgængelige fra siden ved montering.
- **4. kanal til water-strip separat:** unødvendig — strippen deler
  refill-kanalen (den er vandtæt og måler netop vand; påfyldnings-strøm
  forbi den er uproblematisk).

## Implementation notes

- `params.scad`: `channel_{cable,hose,refill}_{angle,d}`, `cup_clearance=1`;
  `ring_gap`, `rim_tab_*`, `hose_pass_*`, `refill_opening_*`, `cable_slot_w`
  fjernet
- `plant_cup.scad`: 2D-profil-arkitektur (`cup_profile_2d()` +
  `channel_cutouts_2d()`), flange med klippede kanal-udskæringer
- `reservoir.scad`: strip-ribber flyttet 0° → 270° og forlænget til fuld
  højde (rotations-lås); rim-tapper fjernet
- Ebase-glands uændret (90°/180° matcher kanalerne lodret)
- Størrelser (ydre Ø / kapacitet / total højde): S 108/261ml/208 —
  M 148/507ml/248 — L 188/832ml/288 — CUSTOM(Ø230-cup) 238/1353ml/233

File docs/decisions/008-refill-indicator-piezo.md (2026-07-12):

# ADR 008 — Refill-indikator via piezo buzzer

**Status:** Accepted
**Dato:** 2026-06-12

## Context

Krukken står inde i en pyntepotte — elektronikken (inkl. WS2812 status-LED) er skjult. Når brugeren fylder reservoiret via refill-åbningen, er der ingen feedback om hvornår det er fuldt. Risiko: overfyldning (vand løber over notch-kanten) eller unødigt hyppige små påfyldninger.

HomeKit-appen viser vandstand, men at stå med en vandkande i én hånd og en iPhone i den anden er dårlig UX. Vi har allerede en kapacitiv water level strip der måler kontinuert — vi mangler kun en lokal feedback-kanal.

## Decision

**Passiv piezo buzzer på D2 (GPIO2), drevet med PWM via ESP32 LEDC.**

Firmware-flow (implementeres i Fase 1):

1. `sensor_task` detekterer **refill-mode**: vandstand stiger >5 procentpoint inden for 10 sek
2. I refill-mode: kort beep ved hver 25%-milepæl (25/50/75%) — stigende tone-pitch med vandstand
3. Ved ≥95%: **dobbelt-beep** = "stop påfyldning"
4. Refill-mode forlades når vandstand har været stabil i 30 sek

**Skala-reference (ADR 009):** 100% = **overflow-niveau** (det fysiske hul i
reservoir-væggen, 8mm under cup-bund). Buzzeren advarer altså FØR vandet når
overflow — overflow-hullet er sidste fysiske forsvarslinje, buzzeren den
første. `adc_full` kalibreres ved overflow-niveau (se calibration.md).

Buzzeren genbruges desuden til fejl-signalering:
- Lav buzz (200 Hz, 1 sek) ved profil/hardware-mismatch (fx orkide-profil uden load cell, ADR 004)
- Tre korte beeps ved float-switch low-water alarm (suppleret af HomeKit-notifikation)

## Consequences

### Positive

- **Hands-free refill-UX**: brugeren hælder vand og lytter — ingen app, ingen synskontakt med skjult elektronik
- **Billigt**: ~5 DKK, én GPIO, intet CAD-arbejde (buzzer sidder i electronics base; lyd slipper ud gennem cable gland-åbninger og pyntepotte)
- **Passiv buzzer + PWM** giver tone-kontrol (pitch-stigning = intuitivt "snart fuldt"-signal)
- Genbrugelig fejl-kanal for alle alarm-tilstande

### Negative

- **D2 er ikke længere reserve**: pin-budgettet på XIAO ESP32-C6 er nu 100% allokeret. Næste sensor (fx DS18B20 vand-temp) kræver I2C-expander eller pin-deling.
- Lydstyrke gennem pyntepotte skal valideres i Fase 3 (mitigation: lydhul i electronics base-væg hvis for dæmpet)
- Buzzer-lyd kan være irriterende — derfor KUN aktiv i refill-mode og ved fejl, aldrig periodisk

### Alternativer overvejet

- **LED light pipe** (transparent stav fører WS2812-lys op til synlig kant): lydløs, men kræver CAD-ændring + synligt element. Noteret som v1.1 CAD-TODO i [pot/cad/source/README.md](../../pot/cad/source/README.md) — kan supplere buzzeren senere.
- **Kun HomeKit**: forkastet som primær (dårlig hands-free UX), men fungerer som sekundær kanal.
- **Aktiv buzzer** (fast frekvens, simplere drive): forkastet — passiv giver pitch-variation for samme pris.

## Implementation notes

- Pin: D2 / GPIO2 (PWM-capable via LEDC)
- Driver: LEDC channel, 50% duty, frekvens 1-4 kHz for beeps (resonans for små piezo-discs ligger typisk ~2-4 kHz)
- API i `pot/firmware/src/buzzer.h`: `buzzer_init()`, `buzzer_beep(freq_hz, duration_ms)`, `buzzer_pattern(BUZZ_REFILL_PROGRESS | BUZZ_REFILL_FULL | BUZZ_ERROR | BUZZ_LOW_WATER)`
- Buzzer monteres med lydåbning vendt mod en cable gland / ventilations-åbning
- BOM: position 28, generic 12mm passiv piezo disc/buzzer, AliExpress/Conrad

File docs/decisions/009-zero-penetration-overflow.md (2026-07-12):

# ADR 009 — Zero-penetration reservoir + fysisk overflow-beskyttelse

**Status:** Accepted
**Dato:** 2026-07-13

## Context

To relaterede problemer blev identificeret efter variant A-implementeringen:

**1. Overfyldnings-risiko (rejst af bruger):** Cuppen har drænhuller i bunden og hænger nedsænket i reservoiret. Overstiger vandstanden cup-bund-niveauet, suger jorden sig mæt gennem hullerne → vandlogging → rodforrådnelse. Den eneste beskyttelse var software (buzzer-beep + HomeKit-visning) — utilstrækkeligt mod en distraheret påfyldning.

**2. Lækage-punkter under vandlinjen (fundet ved gen-inspektion):**
- Water-strip "slotten" skar radialt HELT gennem reservoir-væggen (z=8-58) — åbent hul under vandlinjen
- Pump-porten var et åbent Ø8-hul i reservoir-bunden med en slange igennem — vand siver langs slangen ned mod elektronikken
- Sensor-kabler (soil, strip, float) havde ingen designet vej fra reservoir/cup ned til elektronikken overhovedet

Fælles mønster: enhver gennemføring under vandlinjen er et lækage-punkt der kræver tætning (grommets, glands, O-ringe) som kan fejle over måneder.

## Decision

### A. Zero-penetration princip

**Reservoiret har INGEN gennemføringer under vandlinjen.** Bund og væg er 100% tætte (én solid print). Alle slanger og kabler ruter:

```
[cup/reservoir-features] → op gennem RING-GABET → gennem ÅBNINGER I CUP-FLANGEN
  → ned UDVENDIGT langs reservoiret → ind i ebase via SIDE-GLANDS
```

Konkret vinkel-allokering (set oppefra, håndhævet af rotations-indexering):

| Vinkel | Flange | Reservoir | Ebase (side) |
|---|---|---|---|
| 0° | — | Water-strip guide-ribber (indvendig) | PG7 gland: USB-C |
| 45° | — | — | Drænhul (fail-safe) |
| 90° | Kabel-slids (åben mod kant) | Float-klips i bund | PG7 gland: sensor-kabler |
| 180° | Slange-åbning Ø14 | — | PG9 gland: 2× Ø6 slanger |
| 270° | Refill-åbning | **Overflow-hul** | — |
| 315° | Index-notch (underside) | Index-tap (rim) | — |

- **Water-strip**: holdes af to printede guide-ribber på indervæggen (additivt — intet hul). Kabel op gennem ring-gab.
- **Float switch**: sidder i en print-integreret klips-ring i bunden. Float-kabler er vandtætte; kablet går op gennem vandet/ring-gabet.
- **Pumpe-slanger**: sugeslangen hænger ned i vand-zonen gennem ring-gabet (vægtet ende); trykslangen går op samme vej og ind i cup-toppens side-hul. Begge passerer flangens Ø14-åbning og løber udvendigt ned til ebase's PG9-gland.
- **Rotations-indexering**: tap på reservoir-rim (315°) + notch i flange-underside sikrer at alle åbninger altid flugter.

### B. Fysisk overflow-beskyttelse

**Overflow-hul (Ø5) i reservoir-væggen ved 270°, 8mm under cup-bund-niveau.** Fyldes der forbi, løber overskuddet ud i pyntepotten i stedet for op i jorden. Placeringen lodret under refill-åbningen betyder at overløb ses ØJEBLIKKELIGT mens man hælder.

Konsekvens for kapacitet: max-fill = overflow-niveau → ~814 ml (var ~1018 ved cup-bund-niveau). Stadig 2-3 ugers Monstera-forbrug.

Suppleret af:
- **LECA-lag** (2-3cm lerkugler) i cup-bunden — bryder kapillær kontakt selv ved kortvarig vandkontakt (assembly-guide)
- **Buzzer-tærskler (ADR 008)** relativt til overflow-niveau: 100% = overflow, dobbelt-beep ved 95%
- **Kalibrering**: `adc_full` for water-strip måles ved overflow-niveau — entydigt fysisk referencepunkt

## Consequences

### Positive

- **Nul tætnings-punkter under vand**: lækage-risikoen for elektronikken reduceres fra "flere gaskets skal holde i årevis" til "PETG-printet skal være vandtæt" (kontrollerbart med 3 perimeters + vandtest)
- **Fysisk (ikke software-) beskyttelse mod overfyldning** — virker også ved firmware-crash, sensor-fejl, eller ignoreret buzzer
- **Øjeblikkelig refill-feedback**: overløb ses ved påfyldningshullet
- **Simplere samling**: ingen grommets/møtrikker under vandlinjen; float klipses bare i
- **Entydig sensor-kalibrering**: 100% = overflow-niveau

### Negative

- **Synlige slanger/kabler i ring-gabet og udvendigt** ned til ebase — skjules af pyntepotten, men mindre "integreret" look
- **Kapacitet reduceret ~20%** (814 vs 1018 ml)
- **Overløb ender i pyntepotten** — brugeren skal tømme den ved gentagen overfyldning (acceptabelt: det ER fejl-signalet)
- **Flangen er nu funktionelt kritisk** (åbninger + indexering) — mistes/knækkes den, virker ruteringen ikke
- **Sugeslangen hænger frit** i vand-zonen — kræver en lille vægt/sinker på enden (tilføjet BOM-note)

### Alternativer overvejet

- **Tætnede bund-gennemføringer** (grommets/glands under vandlinjen): forkastet — flere fejlpunkter, sværere samling, og PG-glands i en 3mm printet bund er upålidelige over tid.
- **Tør kabel-skakt integreret i reservoir-væggen** (lodret lukket kanal): elegant men kompleks print-geometri (lange lukkede hulrum = support-problemer), og løser ikke float/strip-montering. Kan genovervejes i v2 custom-design.
- **Kun software-beskyttelse mod overfyldning**: forkastet — utilstrækkeligt, jf. context.

## Implementation notes

- CAD: `reservoir.scad` (overflow, ribber, float-klips, index-tap), `plant_cup.scad` (flange-åbninger, index-notch), `electronics_base.scad` (lukket top, 3 side-glands), `params.scad` (vinkel-allokering dokumenteret i header-kommentar)
- Firmware: refill-detection (ADR 008) skal bruge overflow-relateret skala; `adc_full` kalibreres ved overflow-niveau
- BOM: PG9-gland til slanger (pos 23 udvidet), LECA, slange-sinker

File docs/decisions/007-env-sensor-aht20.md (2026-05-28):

# ADR 007 — AHT20 environmental sensor som standard v1-komponent

**Status:** Accepted
**Dato:** 2026-05-27

## Context

Soil moisture sensoren reagerer på *konsekvensen* af tørt klima (jord der hurtigt tørrer ud), men ikke på *årsagen*. Det betyder vi har et **reaktivt** vandingssystem — det vander efter jorden er nået til tørt, ikke før.

For sensitive planter (Peace Lily der hænger ved tørke, African Violet med fuzzy blade) er reaktiv vanding suboptimal. En temperatur- og fugtighedssensor giver flere muligheder:

1. **Predictive watering** — pre-vand før plant stress sker
2. **VPD-baseret dose-justering** — Vapor Pressure Deficit er den fysiologisk korrekte metric for plantens transpirationskrav. Plant transpirerer ~2× mere ved 28°C/30% RH end ved 22°C/50% RH.
3. **Reservoir-fordampningsforecast** — i tørt indeklima fordamper reservoiret hurtigere; advare om refill før det er kritisk
4. **HomeKit value-add** — rumtermometer + hygrometer som biprodukt
5. **Bedre debug-info** — sensor-drift fra temperatur kan korrigeres aktivt i firmware

## Decision

Vi tilføjer **AHT20 temperatur+humidity sensor** som **STANDARD v1-komponent** (ikke optional som load cell).

Begrundelse for "standard" frem for "optional":
- AHT20 er universelt nyttigt for ALLE planter, ikke kun en undergruppe (i modsætning til load cell som kun er nødvendigt for orkide)
- Cost er lav (~25 DKK)
- Pin-budget på XIAO ESP32-C6 tillader det (vi har stadig 1 reserve-pin)
- Pris-billigere at gøre det rigtigt fra start end at tilføje senere (kræver ompositionering af komponenter)

### Pin-rearrangement

AHT20 er ægte I2C (ikke HX711's pseudo-2-wire) og skal helst på SDA/SCL-default pins for at undgå pin-conflict med ESP-IDF I2C-driver. Det betyder HX711 skal flyttes.

Vi udnytter at ESP32-C6 har **native USB Serial/JTAG**: ESP-IDF console kan routes til USB-C i stedet for UART. Det frigør D6/D7 (UART TX/RX) til HX711.

| Pin | Før | Efter |
|---|---|---|
| D4 | HX711 SCK | **AHT20 SDA** |
| D5 | HX711 DOUT | **AHT20 SCL** |
| D6 | UART TX (debug) | **HX711 SCK** |
| D7 | UART RX (debug) | **HX711 DOUT** |
| Console | UART D6/D7 | **USB-CDC** (via `CONFIG_ESP_CONSOLE_USB_SERIAL_JTAG=y`) |

Se [wiring-diagram.md](../../pot/hardware/breadboard/wiring-diagram.md) for fuld opdateret pin-mapping.

### VPD-aware dose-modifikator (v1.x firmware)

Firmware tilføjer en VPD-baseret skalering af `dose_ml`:

```c
// Tetens formula for saturation vapor pressure (kPa)
float es = 0.611f * expf(17.27f * temp_c / (temp_c + 237.3f));

// Vapor Pressure Deficit
float vpd = es * (1.0f - rh_pct / 100.0f);

// Reference: 22°C / 50% RH ≈ 1.3 kPa (komfortabelt indeklima)
// Skaler dose lineært, clampet til [0.5, 2.0] for sikkerhed
float scale = clamp(vpd / 1.3f, 0.5f, 2.0f);

uint16_t actual_dose_ml = profile.dose_ml * scale;
```

Aktiveres per profil via et `vpd_aware` flag (default `true` for sensitive profiler, `false` for succulenter hvor små doser er kritiske).

## Consequences

### Positive

- **Predictive vanding** mulig — pre-vand ved varm/tør forventning før plant lider
- **VPD-baseret dose** matcher plantens reelle transpirationsbehov
- **Reservoir-fordampning** kan modelleres → bedre refill-prediction
- **Termisk drift-kompensation** af HX711 bliver mulig (temp er nu kendt → korrektion)
- **Ekstra HomeKit-entiteter** (rumtemp + RH) → værdi som klimasensor i hjemmet
- **Negligibel strøm** — AHT20 standby ~2 µA, active ~1.5 mA i 80ms per måling

### Negative

- **+1 komponent** at lodde, +25 DKK i BOM
- **Pin-rearrangement** kræver opdatering af wiring-diagram + firmware konstanter
- **USB-CDC console** i stedet for UART — nyt for nogle udviklere, men ESP32-C6 håndterer det native
- **Firmware kompleksitet** — VPD-aware logik tilføjes til control_task

### Alternativer overvejet

- **BME280** (~40 DKK): tilføjer barometer som vi ikke har brug for. Overkill.
- **SHT41** (~60 DKK): højere præcision (±0.2°C, ±1.5% RH), men marginal benefit for vores brug-case.
- **Skip helt og lave det optional v1.1**: forkastet — bruger valgte eksplicit "gør det ordentligt første gang"; det er billigere og enklere at integrere nu end at tilføje senere.
- **Behold UART, drop manual button eller WS2812 LED**: overvejet, men ESP32-C6 USB-CDC er moden og giver bedre dev-oplevelse end UART.

## Implementation notes

### Hardware

- AHT20 modul (Adafruit, DFRobot, eller AliExpress generic) ~25 DKK
- 4-pin breakout: VCC (3.3V), GND, SDA, SCL
- 4.7kΩ pull-up resistorer på SDA og SCL (inkluderet på de fleste breakout-boards; tjek databladet)
- Placering: et sted i electronics base hvor luften kan cirkulere (ikke direkte over varmegenererende komponenter)

### Firmware

- I2C-driver: ESP-IDF `i2c_master.h` (v5.x API)
- AHT20 address: 0x38
- Måling: trigger 0xAC 0x33 0x00 → vent 80ms → læs 6 bytes (status + 20-bit hum + 20-bit temp + CRC)
- Sample-rate: 1 reading per 60. sek (rum-klima ændres langsomt)
- Se [pot/firmware/src/temp_humidity.h](../../pot/firmware/src/temp_humidity.h) for API.

### USB-CDC console enablement

I `sdkconfig.defaults`:
```
CONFIG_ESP_CONSOLE_USB_SERIAL_JTAG=y
CONFIG_ESP_CONSOLE_SECONDARY_NONE=y
```

Console-output (ESP_LOGI etc.) vil derefter komme via USB-C portens CDC-interface. På macOS dukker den op som `/dev/cu.usbmodem*`.

### Failure mode

Hvis AHT20 ikke svarer på I2C ved boot: firmware logger warning, sætter `env_sensor_available = false`, og fortsætter med fixed-dose (no VPD adjustment). Brugeren får advarsel i HomeKit men systemet kører videre. Dette giver graceful degradation hvis brugeren bygger uden AHT20.

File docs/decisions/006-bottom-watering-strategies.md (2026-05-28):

# ADR 006 — Bottom-watering strategier: wick i v1, soak-tray i pot-orchid (v2)

**Status:** Accepted
**Dato:** 2026-05-27

## Context

Nogle planter har naturlig præference for at blive vandet nedefra:

- **Stærk præference** (top-vanding skader): African Violet, Gloxinia, Begonia Rex, Cyclamen, Streptocarpus — fuzzy/tykke blade rådner ved vand-kontakt.
- **Foretrækker bottom-watering**: Orkide (bark-medium suger bedre ved nedsænkning), succulenter med tæt rosette (Echeveria, Sempervivum, Haworthia, kaktus), Snake plant, Pilea peperomioides, Air plants.
- **Top-vanding fungerer fint**: Monstera, Pothos, Philodendron, Peace Lily, Spider plant, Ficus, ZZ plant, Calathea.

Vores nuværende v1-design (top-drip via drip-ring) er ideelt for "top-vanding fungerer fint"-kategorien, men suboptimalt for resten. Specifikt:

- `succulent`-profil top-drypper på 15ml/3 dage — Aloe tolererer det, men Echeveria/Sempervivum kan rådne i kronen
- `orchid_phalaenopsis`-profil bruger 3×10s drip-bursts som approximation af soaking — det er ikke ægte soaking (nedsænkning i 10-15 min)

## Decision

Vi tilføjer to bottom-watering strategier i to faser:

### v1 (denne iteration): Wick-metoden

**Cotton/nylon-snor passerer gennem center-drænhullet i plant_cup, hængende fra jord ned i reservoir-vandet.** Capillær virkning trækker vand op til jorden 24/7 — passivt, ingen pumpe-aktion nødvendig.

- Wick = 4mm flettet bomulds- eller nylon-snor, 10-15cm lang
- 5-7cm i jorden (helt op til soil-overfladen), 5-7cm i reservoir-vandet
- Tilbehør i BOM, ingen CAD-ændringer — wick går gennem eksisterende 4mm center drænhul

**Pumpen er stadig aktiv** — den fylder soil-side hurtigt ved akut tørke (kompenserer for langsom wick-tilførsel), og kan også droppe drip-vanding helt for planter der KUN skal have bottom-watering (sæt `dose_ml = 0` i custom profil).

### v2: Dedikeret pot-orchid med soak-tray

For orkider (og potentielt store succulenter) laves en **separat krukke-variant** i `pot-orchid/` mappen med:

- Ekstra tray omkring plant cup der kan oversvømmes via pumpen
- 10-15 min soak-cyklus → derefter tømning via solenoid-ventil eller passiv overflow
- Mimicker manuel orkide-soaking præcist

Bygges IKKE i v1. Planlægges parallelt i `pot-orchid/` mens v1 valideres.

## Consequences

### Positive

- **Bredere plantestøtte i v1**: African Violet, Calathea, Peace Lily og fugt-elskere kan nu håndteres godt med wick.
- **Lavt cost/kompleksitet**: wick koster ~20 DKK for et 2m batch, ingen hardware/firmware ændring.
- **Bagudkompatibel**: brugere kan vælge at IKKE bruge wick — designet fungerer som før.
- **Klart upgrade-path**: pot-orchid er separat track, ikke kompromis i v1-design.

### Negative

- **Wick = konstant tilstedeværende fugt**: succulenter (der vil have tørre perioder) skal IKKE bruge wick. Brugeren skal vide hvilke planter passer.
- **Wick-rengøring**: efter måneder/år samler wick aflejringer og bør skiftes (~årligt).
- **Soil moisture sensor reading med wick**: jorden er typisk fugtigere når wick er installeret. Profilernes `target_min_pct` skal eventuelt justeres op (~10% point).

### Alternativer overvejet

- **Wick som default i alle planter**: forkastet — succulenter/orkide vil ikke have konstant fugt; wick er opt-in.
- **Soak-tray i v1**: forkastet — kræver solenoid + ekstra tray + drain-logik. Bevarer v1-scope simpelt; flyttes til pot-orchid v2.
- **Sub-irrigation (cup nedsænket i reservoir)**: forkastet — kræver redesign af cup/reservoir-relations. Wick giver samme effekt med mindre ændring.

## Implementation notes

### Wick installation (v1)

1. Vælg ~15cm flettet cotton- eller nylon-snor (4mm tykkelse).
2. Inden plant cup fyldes med jord: træd wick gennem center-drænhullet. 6-8cm går op i jord-zonen, 6-8cm hænger ned.
3. Læg lidt jord under wick i cup bunden så den ikke flytter sig.
4. Fyld resten af jorden om wick'en.
5. Når cup placeres i reservoir, skal wick-enden hænge ned i vandet (ikke kileknækket).

### Profile-tilpasning ved wick-brug

For planter med wick:

- Hæv `target_min_pct` med +5 til +10 (jorden er konstant fugtigere)
- Hæv `cooldown_min` betydeligt (pumpen behøver kun supplere ved akut tørke)
- For ren bottom-watering: sæt `dose_ml = 0` (kun wick, ingen pump-drip)

Dokumenteres i [plant-profiles.md](../plant-profiles.md) per relevant profil.

### Pot-orchid (v2) planlægning

Se [../../pot-orchid/](../../pot-orchid/) for løbende design-noter. Bygges først efter v1 er valideret.

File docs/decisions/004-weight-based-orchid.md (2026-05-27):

# ADR 004 — Vægt-baseret detektion til orkider (optional hardware)

**Status:** Accepted
**Dato:** 2026-05-27
**Opdateret:** 2026-05-27 — load cell sizing + optional hardware-strategi

## Context

Brugeren ønsker en plantekrukke der kan håndtere flere plantetyper med vidt forskellige vandbehov:

- **Monstera, Pothos, Peace Lily** (tropiske, jord-baseret): regelmæssig vanding, kapacitiv soil moisture sensor fungerer fint. Disse planter kan veje 3-10+ kg når voksne.
- **Crassula Uvata, Aloe Vera** (succulenter): meget lidt vand, lange tørre perioder. Soil moisture sensor virker i kaktus-jord. Typisk 0.5-2 kg.
- **Orkide (Phalaenopsis)**: bark-medium, ikke jord. Bark-medium har **ekstrem heterogen struktur** — kapacitiv sensor giver upålidelige værdier afhængigt af kontaktflade. Orkider vandes typisk ved **nedsænkning (soaking)** i 10-15 min, ikke kontinuerlig drip. Typisk 0.3-1 kg.

Et naïvt design med kun soil moisture sensor + drip pump dækker dårligt orkider. Men *vægt-detektion er kun nødvendig for orkider* — alle jord-baserede planter klarer sig med moisture sensor alene.

## Decision

### Vægt-detektion: kun for orkider, ikke for jord-planter

Vi tilføjer **HX711 ADC + bar load cell 5kg** som **OPTIONAL hardware**. Profilerne styrer hvilke krukker der har brug for det:

- **DETECT_MOISTURE** (Monstera, Pothos, Peace Lily, succulenter): kapacitiv soil sensor er primær og eneste signal. **Ingen load cell nødvendig.** Krukken står direkte på bord eller på rubber feet under electronics base.
- **DETECT_WEIGHT** (Orkide): HX711 + load cell er primær signal. **Load cell er påkrævet.** Krukken hviler på load_cell_mount platform.
- **DETECT_HYBRID** (optional for succulent power-users): begge signaler — moisture primær, weight som sanity check ("hvis jord er dry OG vægt er faldet, så vand"). Load cell krævet hvis valgt.

### Load cell kapacitet: 5kg (ikke 1kg)

1kg løste teknisk orkide-cases (orkide vejer ~1 kg max), men 5kg giver væsentlig safety margin og koster det samme:

- Orkide max ~1 kg
- Succulent (med jord + krukke) ~1-3 kg
- 5kg = 2-5× safety margin → ingen risiko for over-load skade

Bemærk: HX711 24-bit ADC giver ~0.3 mg/LSB ved 5kg fuldskala, hvilket er rigeligt resolution til at detektere vand-tab på 5-50g.

### Hardware-konfiguration per profil

| Plante | Profile | Soil sensor | HX711 + load cell | Cup-størrelse |
|---|---|---|---|---|
| Monstera | `monstera` | ✓ | ✗ (overflødig) | M eller L |
| Pothos | `pothos` | ✓ | ✗ | S, M eller L |
| Peace Lily | `peace_lily` | ✓ | ✗ | M eller L |
| Succulent (Crassula, Aloe) | `succulent` | ✓ | ✗ default, ✓ optional | S eller M |
| Orkide | `orchid_phalaenopsis` | (ignoreres) | ✓ påkrævet | S |
| Custom | `custom` | bruger-config | bruger-config | enhver |

## Consequences

### Positive

- **Lavere build-cost for store planter:** Monstera/Peace Lily-brugere sparer ~65 DKK (HX711 + load cell) og forenkler samling (ingen load_cell_mount print).
- **Mere realistisk vægt-sizing:** 5kg cell håndterer alle relevante use cases uden overload.
- **Modulær arkitektur:** firmware detekterer om HX711 er tilstede ved boot. Hvis ikke → `weight_available = false` flag sættes; profiler der kræver vægt giver advarsel i HomeKit.
- **Skalérbar:** Bruger kan tilføje load cell senere hvis de skifter fra Monstera til orkide.

### Negative

- **Firmware kompleksitet:** to "modes" (with/without weight). HX711-detektion ved boot kræver runtime probe (læs få gange, tjek om værdier ændres).
- **Profilvalg kan fejle:** bruger vælger orkide-profil men har ikke load cell → HomeKit skal vise fejl. Ekstra UX-arbejde.
- **Dokumentation:** brugere skal læse hvilke profiler kræver hvilken hardware.

### Alternativer overvejet

- **Større load cell (10kg) for at dække alle planter:** forkastet — Monstera 5-10kg overloader stadig 10kg load cell over tid; resolution forværres ved at gå større; og store planter behøver ikke vægt-signal pga. moisture sensor virker fint i jord.
- **To krukke-varianter (med/uden load cell):** forkastet til fordel for én modulær design hvor load_cell_mount er optional add-on.
- **Drop orkide-support helt:** forkastet — brugeren ønskede bred plante-kompatibilitet, og orkide-kasen er løsbar med 5kg cell.

## Implementation notes

### Firmware

- HX711 powered ned via SCK held high når ikke i brug (sparer strøm i SED mode).
- Ved boot: prober HX711 ved at læse 3 gange. Hvis værdier identiske eller alle 0x000000/0xFFFFFF → `weight_available = false`.
- Sample-rate: 1 reading per 10 min (vandtab er langsom).
- Moving average over 5 samples for at filtrere vibrations-støj.
- Tare via HomeKit-knap når plante er nyligt vandet → gemmes i NVS som profil-baseline.

### Profile-validering

```c
bool profile_validate(const plant_profile_t *p, bool weight_available) {
    if ((p->mode == DETECT_WEIGHT || p->mode == DETECT_HYBRID) && !weight_available) {
        return false;  // bruger valgte profil der kræver vægt, men hardware mangler
    }
    return true;
}
```

Hvis validering fejler: HomeKit Mode Select cluster reporterer fejl, status-LED bliver gul, og pumpe disables indtil bruger fixer (enten ændrer profil eller installerer load cell).

### Hardware-build

- For Monstera/Peace Lily/store planter: spring `load_cell_mount.scad` over. Tilføj 3-4× stick-on rubber feet (~Ø15mm) til bunden af `electronics_base_lid`.
- For orkide/succulent: print `load_cell_mount.scad` og brug 5kg TAL220 (eller equivalent) med M4-bolte + 2mm spacer-skiver.

### Kalibrering

Samme procedure for 5kg som for 1kg — se [calibration.md](../calibration.md) sektion 5. Brug 1kg standard-vægt (typisk ladestik) som kalibreringsreference.

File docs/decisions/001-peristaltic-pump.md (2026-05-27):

# ADR 001 — Peristaltisk pumpe til vanding

**Status:** Accepted
**Dato:** 2026-05-27

## Context

Plantekrukken skal levere præcis vanddosering i området **5–100 ml** (succulenter til Monstera).
Pumpen skal være:
- Stille (krukken står i stuen)
- Pålidelig over uger/måneder uden tilsyn
- Tolerant overfor tør-kørsel (hvis vandreservoir tømmes før software fanger det)
- Hygiejnisk (ingen alge-vækst direkte i pumpen)

## Decision

Vi bruger en **peristaltisk 12V DC pumpe** (Kamoer KPP eller tilsvarende generisk, ~30 ml/min) drevet via N-channel logic-level MOSFET (IRLB8721) fra ESP32-C6 GPIO.

## Consequences

### Positive

- **Selv-primende**: ingen luft-låse i slangen efter længere stilstand.
- **Dry-run tolerant**: pumpen tager ikke skade af at køre tør (i modsætning til submersible pumper hvor rotoren brænder af uden vand-køling).
- **Vand rører ikke pumpe-mekanikken**: kun en silikoneslange. Eliminerer alger, kalk og vandkemiske angreb. Slangen kan udskiftes uden at åbne pumpehuset.
- **Præcis dosering**: ml/sek er lineær over hele driftsområdet, så simpel kalibrering (kør 10 sek, vej output) giver præcise doseringer ned til ~3 ml.
- **Lavt vandtryk**: behøver ingen tryk-regulator eller solenoid-ventil.

### Negative

- **Højere pris**: ~150 DKK vs ~25-50 DKK for en submersible mini-pumpe.
- **Mekanisk slid**: silikoneslangen i pumpehuset slides over tid (500-2000 timers levetid). Skal udskiftes periodisk — typisk hvert 1-2 år ved vores driftscyklus.
- **Lidt mekanisk klik-støj** mens den kører. Acceptabelt ved 100 sek/dag driftstid.

### Alternativer overvejet

- **Submersible mini-pumpe 5V (~25 DKK)**: forkastet pga. dry-run risiko (kritisk for ubevogtet drift) og direkte vandkontakt → alger/kalk.
- **Solenoid-ventil + tyngdekraft-fed reservoir**: forkastet fordi det kræver reservoir over plantens niveau, hvilket modarbejder "kompakt krukke der bor i pyntepotte"-konceptet.

## Implementation notes

- MOSFET-gate har 10kΩ pull-down for at sikre OFF ved boot.
- 1N5819 Schottky flyback-diode over pumpe-terminaler.
- Pumpe-strøm målt med multimeter ved kalibrering (forventet ~300 mA @ 12V).
- Kalibreringskonstant `pump_ml_per_sec` gemmes i NVS efter første opstart.

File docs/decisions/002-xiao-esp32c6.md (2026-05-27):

# ADR 002 — XIAO ESP32-C6 som MCU

**Status:** Accepted
**Dato:** 2026-05-27

## Context

Plantekrukken skal:
- Tale **Matter over Thread** med Apple HomeKit (via HomePod/Apple TV som Thread Border Router).
- Have **WiFi-fallback** for setup og diagnostik.
- Køre **lavt strømforbrug** så batteri-drift bliver muligt i v2.
- Have nok GPIO til 4 sensorer + pumpe-driver + status-LED + manuel knap.
- Være fysisk **lille** så den passer i krukkens elektronik-base.

## Decision

Vi bruger **Seeed Studio XIAO ESP32-C6** som MCU både til prototype-fase (breadboard) og til endelig integration. Castellated edges tillader direkte lodning på custom PCB i v2 uden re-design.

## Consequences

### Positive

- **Native Thread + Matter + WiFi + BLE 5** i én chip — ESP32-C6 er Espressifs første Thread-capable SoC.
- **USB-C indbygget**: ingen ekstern programmer; flash + monitor via samme kabel som strømforsyning.
- **Kompakt 21×17.5mm** — passer i lille elektronik-kammer uden at dominere PCB-layoutet.
- **Castellated edges** + standard 0.1" pinout giver fleksibilitet: breadboard for prototype, direct-mount for produktion.
- **Tilstrækkelige GPIO**: 11 brugbare pins. Vores brug: 2 ADC (soil + water) + 2 GPIO (HX711) + 1 GPIO (float ISR) + 1 GPIO PWM (pumpe) + 1 GPIO (LED) + 1 GPIO (knap) = 8 pins, 3 til overs.
- **Bredt economy**: ~80 DKK fra flere distributører (Mouser, Digi-Key, Elektor).

### Negative

- **Nyere chip** (2024): ESP-IDF support er stabilt men ESP-Matter SDK på C6 har stadig nogle rough edges. Dokumentation til Thread Sleepy End Device på C6 er ikke perfekt.
- **Færre Thread-eksempler i wild** end nRF52840 — community-resources er mindre.
- **ADC-præcision** er begrænset (12-bit ENOB ~10-11) — fint til vores ratio-baserede moisture-målinger, men ikke til hi-precision ADC-arbejde.

### Alternativer overvejet

- **ESP32-C6-DevKitC-1** (Espressif official): mere robust til prototyping, men 3x større fysisk. Forkastet pga. størrelse.
- **Nordic nRF52840** (fx Adafruit Feather): bedre Thread-modenhed, men mangler WiFi og kræver separat programmer. Forkastet pga. WiFi-mangel + større barrier til entry for hobbyist.
- **ESP32-H2** (Thread+BLE only, ingen WiFi): forkastet — WiFi-fallback til diagnostik er værdifuldt.

## Implementation notes

- Pin-mapping dokumenteret i [../../pot/hardware/breadboard/wiring-diagram.md](../../pot/hardware/breadboard/wiring-diagram.md).
- ESP-Matter SDK pinnes til specifik git-tag i `platformio.ini` for at undgå breaking changes.
- Power-budget i [main plan sektion 8](../../.claude/plans/...) viser at C6 i Sleepy End Device mode gør batteri-drift realistisk for v2.

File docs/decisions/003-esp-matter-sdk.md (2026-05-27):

# ADR 003 — Firmware-stack: PlatformIO + ESP-IDF + ESP-Matter SDK

**Status:** Accepted
**Dato:** 2026-05-27

## Context

Firmware skal:
- Drive sensor-sampling, pumpe-styring, plant-profile logik, og Matter cluster-eksponering.
- Køre på ESP32-C6.
- Være vedligeholdelsesvenlig over tid.
- Tillade brugeren at lære Matter-stacken (eksplicit ønske).

Tre rimelige stacks blev overvejet:

1. **ESPHome** (YAML + lambda C++) — hurtig prototyping, Matter indbygget.
2. **PlatformIO + ESP-IDF + ESP-Matter SDK** (C/C++) — fuld kontrol, mere boilerplate.
3. **Arduino framework + Matter library** — kendt territorium, men umodne Matter-libs.

## Decision

Vi bruger **PlatformIO som build-system, ESP-IDF som framework, og Espressifs officielle ESP-Matter SDK** som Matter-stack. Sproget er C/C++ (matcher brugerens præferencer i `~/.claude/CLAUDE.md`).

## Consequences

### Positive

- **Fuld kontrol over Matter-stacken**: vi kan implementere custom clusters (fx "plant care" cluster for soil moisture targets), justere endpoint-strukturen, og finetune Thread Sleepy End Device timing.
- **PlatformIO**: bedre IDE-integration (VS Code/Antigravity) end råt ESP-IDF CLI, og let at versionere via `platformio.ini`.
- **Officiel SDK fra Espressif**: følger Matter-specifikationen tæt, opdateres med nye Matter-versioner.
- **Læringsudbytte**: brugeren får hands-on med både Matter-protokollen og FreeRTOS, hvilket var et eksplicit projektmål.
- **C/C++**: matcher brugerens vante sprog; kan dele kode med embedded-projekter i andre repos.

### Negative

- **Mere boilerplate**: Matter device-init kræver ~200 linjer setup-kode vs ~20 linjer i ESPHome YAML.
- **Stejlere læringskurve**: ESP-Matter SDK har ufuldstændig dokumentation. Forvent at læse Espressifs eksempler grundigt.
- **Længere iterations-cyklus**: kompilering tager 1-3 min vs ESPHomes hot-reload.
- **OTA-flow skal bygges manuelt** vs ESPHomes built-in OTA.

### Alternativer overvejet

- **ESPHome**: forkastet fordi brugeren eksplicit ønskede C/C++ + ESP-Matter SDK. ESPHome er stadig en glimrende option for ikke-C/C++ brugere; vi kan altid migrere senere hvis vedligeholdelse bliver byrdefuld.
- **Arduino + Matter**: forkastet — Arduino-Matter libraries er stadig umodne (2026 Q1), og man får ofte ESP-IDF/Arduino mismatches der spilder tid.

## Implementation notes

- `platformio.ini` pinner `framework = espidf` og `platform = espressif32 @ ^6.5.0`.
- `esp-matter` inkluderes som ESP-IDF component via `idf_component.yml`.
- ESP-Matter SDK version pinnes til specifik git-tag (ikke `main`) for reproducerbare builds.
- FreeRTOS-tasks holder Matter event-loop separat fra sensor/control-logik.
- HomeKit-eksponering via standard Matter clusters: `Humidity Sensor`, `Leak Detector`, `On/Off Switch`, `Mode Select`.

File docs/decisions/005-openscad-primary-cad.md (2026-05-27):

# ADR 005 — OpenSCAD som primær CAD

**Status:** Accepted
**Dato:** 2026-05-27

## Context

Plantekrukken har modulært design med flere størrelser (S/M/L plantebeholdere, 700ml/1500ml reservoirs), og brugeren ønsker at samarbejde med Claude Code om CAD-iterationer. Brugeren har studielicens til Fusion 360 men er åben overfor alternativer.

Tre kandidater:

1. **OpenSCAD** — tekstbaseret, parametrisk, gratis, git-friendly diffs.
2. **Fusion 360** — GUI, kraftfuldt, men binære `.f3d`-filer.
3. **FreeCAD** — open-source GUI med parametrisk pipeline; `.FCStd` er binær men mere git-tolerant.

## Decision

Vi bruger **OpenSCAD som primær CAD-værktøj** for alle 3D-printede dele i projektet. Fusion 360 bevares som backup for komplekse organiske geometrier hvis OpenSCAD bliver upraktisk for en specifik del.

## Consequences

### Positive

- **Claude Code kan redigere CAD direkte**: `.scad` er tekstkode, så jeg kan iterere på designet uden eksport/import-flow.
- **Parametrisk i én fil**: `params.scad` definerer alle dimensioner. Skift `cup_size = "M"` → `cup_size = "L"` → re-eksporter STL → ny størrelse klar.
- **Git-friendly**: meaningful diffs på CAD-ændringer. `+ cup_diameter = 140` er klart hvad der skiftede.
- **Reproducerbar build**: STL kan re-genereres fra `.scad` enhver tid, så vi behøver ikke committe binære STL'er (men kan gøre det for convenience).
- **Genbrug via modules**: fælles geometri (M3-insert holes, gasket-grooves) leves i `shared/cad-lib/` og inkluderes med `use <...>`.

### Negative

- **Stejlere læringskurve** for brugere vant til GUI. Visualisering kræver F5 re-render.
- **Mindre intuitiv for organiske former** (sweeps, fillets, lofts). OpenSCAD er bedst til boxy/CSG-baseret geometri — heldigvis matcher det vores krukke-design.
- **Render-tid** for komplekse modeller (>1 min for F6 full render). For interactive design bruger vi F5 preview.
- **STEP-eksport er begrænset**: hvis vi senere vil sende designet til professionel fabrikation, kræver det Fusion-import først.

### Alternativer overvejet

- **Fusion 360 primær**: forkastet pga. binære filer (umulig diff i git) og kræver eksport-step før Claude Code kan se ændringer.
- **FreeCAD**: mellemting; afvist pga. modnnings-issues i topology naming og at OpenSCAD passer bedre til vores parametriske brug-case.
- **build123d / CadQuery (Python-baseret CAD)**: lovende, men kommunity og dokumentation er mindre. Holdt som "kig på i v2 hvis OpenSCAD-syntax bliver byrdefuld".

## Implementation notes

- Alle dimensioner i `pot/cad/source/params.scad` (single source of truth).
- Hver komponent (plant_cup, reservoir, electronics_base, load_cell_mount) har sin egen `.scad`-fil der `use`r params.
- STL-eksport: `openscad -o pot/cad/stl/reservoir-700ml.stl pot/cad/source/reservoir.scad`. Kan automatiseres via Makefile.
- Naming convention for STL: `<part>-<variant>.stl`, fx `plant-cup-M.stl`, `reservoir-1500ml.stl`.
- Prusa-slicer profiler gemmes som `.3mf` i `pot/cad/prusa-profiles/` med material + layer-settings indlejret.
- Hvis en del bliver for kompleks for OpenSCAD: design i Fusion → eksporter STEP → konverter til STL → læg i `pot/cad/stl/` med en `<part>-source-fusion.md`-fil der dokumenterer hvor source-filen ligger.

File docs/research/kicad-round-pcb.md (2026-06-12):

# Research: KiCad til custom rund PCB (v2)

**Status:** Research-note — implementeres i v2 (custom PCB-fase). Skrevet 2026-06-12.

## Konklusion (TL;DR)

Rund PCB er **fuldt understøttet i KiCad** uden plugins eller tricks. Workflowet er modent, og vi kan genbruge geometri direkte fra vores OpenSCAD-design så PCB'en passer perfekt i electronics_base. Ingen merpris hos prototype-fabrikanter.

## Hvordan: rund board-outline i KiCad

Board-omridset i KiCad defineres af grafiske objekter på **Edge.Cuts**-laget. En lukket form = board-kant; lukkede former INDE i den ydre form = udskæringer (cutouts).

For en cirkulær PCB:
1. PCB Editor → vælg Edge.Cuts-laget
2. "Add graphic circle"-værktøjet → tegn cirkel med præcis diameter
3. Mounting holes: M3-huller placeret så de matcher electronics_base boss-positioner

Krav: omridset skal være en **kontinuert lukket form** (endepunkter skal mødes præcist), ellers fejler DRC/plot.

## DXF-flow fra OpenSCAD (anbefalet)

Vi kan garantere at PCB'en passer i kammeret ved at generere outline fra samme parametriske kilde:

```scad
// pcb_outline.scad — 2D-projektion til DXF-eksport
include <params.scad>

// PCB-diameter: indvendig kammer-radius minus clearance
pcb_clearance = 1.5;
pcb_d = ebase_outer_d - 2 * ebase_wall - 2 * pcb_clearance;

difference() {
    circle(d = pcb_d);
    // M3 mounting holes ved boss-positioner
    for (a = [0, 90, 180, 270])
        rotate([0, 0, a])
            translate([ebase_outer_d / 2 - ebase_wall - 4, 0])
                circle(d = 3.2);
}
```

```bash
openscad -o pcb_outline.dxf pcb_outline.scad
```

I KiCad: File → Import → Graphics → vælg DXF → placér på Edge.Cuts. Mounting holes kan også importeres, eller placeres som footprints (`MountingHole_3.2mm_M3`).

**Fordel:** ændrer vi `ebase_outer_d` i params.scad, re-eksporterer vi DXF og PCB-outline følger med. Single source of truth bevares.

## Kode-defineret KiCad: circuit-synth

Vi har adgang til `circuit-synth` (Python → KiCad skematik/netlist/PCB). Det matcher projektets git-friendly filosofi (ADR 005: OpenSCAD over Fusion af samme grund):

- Skematik defineres i Python → versioneret som kode, meningsfulde diffs
- Genererer KiCad-projektfiler + netlist + BOM
- Claude Code kan redigere kredsløbet direkte

**Vurdering:** Stærk kandidat til v2 PCB-design. Beslutning udskydes til PCB-fasen — men det betyder at vi IKKE behøver tegne skematik manuelt i KiCad GUI.

## v2 PCB design-skitse

| Aspekt | Plan |
|---|---|
| Form | Rund, Ø ≈ 170mm minus clearance (passer ebase indvendigt) |
| Lag | 2-lags (rigeligt til vores lavfrekvente design) |
| MCU | XIAO ESP32-C6 castellated direct-mount (lodde-pads på PCB) |
| Konnektorer | JST-XH langs kanten (soil, water strip, float, HX711, AHT20, buzzer, pumpe) |
| Power | ZY12PDN + MP1584 som moduler (through-hole headers) eller diskret buck on-board |
| Mounting | 4× M3-huller matchende electronics_base bosses |
| Antenne-hensyn | XIAO's antenne skal vende mod kammerets kant, fri for kobber-plane under |

## Produktion

JLCPCB / PCBWay / Aisler håndterer runde boards uden merpris — prisen beregnes af bounding box. 2-lags Ø170mm prototype: ~15-25 USD for 5 stk hos JLCPCB (plus fragt/told).

**OBS:** Ø170mm er stort for en PCB — overvej om PCB'en reelt behøver fylde hele kammeret, eller om en mindre Ø100mm centreret PCB med kabler til kant-monterede komponenter er billigere og enklere.

## Kilder

- [KiCad PCB Editor docs (board outline)](https://docs.kicad.org/9.0/en/pcbnew/pcbnew.html)
- [KiCad forum: How to define the board outline](https://forum.kicad.info/t/how-to-define-the-board-outline-pcb-edge/32166)
- [Wayne and Layne: KiCad PCB edges tutorial](https://www.wayneandlayne.com/blog/2013/02/26/kicad-tutorial-pcb-edges/)

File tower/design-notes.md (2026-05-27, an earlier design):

# Tower Design Notes

**Status:** Initiel design — bliver opdateret løbende mens vi lærer fra plantekrukke-prototypen.

Dette dokument samler designvalg, åbne spørgsmål, og lessons learned der akkumuleres under v1-arbejdet. Når v1 er færdig, vil dette være grundlag for v2-implementering.

---

## Brugerkrav (fra projektopstart)

- **Vægmonteret** — frigør gulvplads
- **Modificeret "3D Printed Hydroponic Tower Garden"**-koncept
- **Stille og automatisk**
- **Beholder med vand i bunden** — ikke ofte genopfyldning
- **Nemt at fylde**: tragt eller åbning i top
- **Water meter sensor** + **gennemsigtigt vindue** til fysisk vand-inspektion
- **Stille pumpe** (akvarie-type)
- **Stikkontakt-baseret** (batteri er ikke krav)
- **Krydderurter** primært, **leafy greens** sekundært

---

## Designvalg (foreløbige)

### Hydroponic-metode

**Foreløbig beslutning:** Vertical drip → drain-and-recirculate.

Vand pumpes fra reservoir op til top → drypper ned gennem plant slots → falder tilbage i reservoir.

| Metode | Pro | Contra |
|---|---|---|
| **Vertical drip (chosen)** | Simpel, ingen kontinuerlig waterflow, nem rens | Risiko for tørre rødder mellem cyklus |
| NFT (Nutrient Film Technique) | Effektivt, lavt vandforbrug | Kontinuerlig pumpedrift, fragmenteres ved strømsvigt |
| DWC (Deep Water Culture) | Rødder altid i vand | Tungt, kræver air-pump for ilt → mere støj |
| Aeroponics | Højeste yield | Mest komplekst, dyrt, tilstoppes |

Beslutning baseres på: stille drift (peristaltisk impossible i denne skala — kræver submersible), og forgivende mht. tørke-tolerance (krydderurter klarer korte tørke).

### Antal plante-slots

**Foreløbig:** 5-7 slots. Hver slot er et standard 2" net cup.

Begrundelse: Prusa XL har 360x360mm print bed. En tower-segment på 200mm højde × 7 slots = 1.4m total højde. Print 3-5 segmenter á 30-40cm.

### Pumpe

**Foreløbig:** Submersible aquarium-pumpe 12V, ~200-400 L/h.

| Kandidater | Flow | Støj | Pris |
|---|---|---|---|
| Eheim CompactON 300 (12V variant) | 300 L/h | Ultra stille | ~250 DKK |
| Generic submersible USB 5V | 100-200 L/h | Lav | ~30 DKK |
| Jebao DC-1200 (overkill) | 1200 L/h | Lav | ~400 DKK |

Submersible passer fordi: hele pumpen sidder i reservoir (vand-køling, ingen prime-issues), og vi behøver høj flow (kontinuerlig recirculation vs pot's diskrete dosering).

### MCU

**Genbruger XIAO ESP32-C6 fra pot.** Samme firmware-skelet (FreeRTOS-tasks), men anden config-mode.

### Sensorer

- **Water level**: Større reservoir → ultralyd JSN-SR04T kunne fungere her (har 25cm dødzone, men reservoir er højere). Eller capacitive strip som i pot, bare længere.
- **Float switch**: ja, samme rolle som i pot (low-water cutoff).
- **pH-sensor**: ? — hydroponic kræver pH 5.5-6.5. Manuel måling er muligt, men automatisk er fancy. Beslut efter v1.
- **EC-sensor**: ? — nutrient concentration. Samme.
- **Temperatur** (vand): hydroponic vand >25°C → bakterie-vækst. Tilføj 1-wire DS18B20 i reservoir.

### Strøm

USB-C PD til 12V (samme som pot), eller direkte 12V barrel jack. Brug eksisterende 12V adapter hvis tilgængelig.

### Lys

**Åbent spørgsmål:** Vinduskarms-lys er tilstrækkeligt for krydderurter, men leafy greens (salat, spinat) trænger mere. LED grow lights tilføjer kompleksitet (timer, control, varme) men kunne være v2-feature.

Tanker:
- Hvis tower placeres ved vindue: skip grow lights i v2, evaluer behov efter 2-3 måneder
- Hvis indvendigt på væg: grow lights nødvendige; planlæg sektion i firmware til time-of-day-styret LED PWM

---

## Åbne spørgsmål (besvares løbende)

- [ ] Skal tower være ét stort print (Prusa XL) eller modulært (flere mindre prints)?
- [ ] Hvordan håndteres rens/skift af planter uden at demontere alt?
- [ ] Hvor placeres elektronikken — i bunden ved reservoir (våd!) eller separat udvendigt?
- [ ] Hvilken nutrient-løsning? (General Hydroponics Flora-serien er standard)
- [ ] Hvordan undgå alger i transparent vandvindue? (UV-LED? Dækfilm? Acceptér rens månedligt?)
- [ ] Skal pumpen køre 24/7 eller cykle? (24/7 er enklest; cyklisk sparer strøm + støj)
- [ ] Strømudtag: bag tower (skjult) eller skal kablet være pænt synligt?
- [ ] Vægmontering: skruer i mur eller free-standing med vægstøtte?

---

## Lessons learned fra pot (opdateres løbende)

*Endnu intet — pot er ikke bygget.*

Pladsholder-sektioner der opdateres efter hver pot-fase:

### Fra Fase 1 (firmware bring-up)
*TBD*

### Fra Fase 2 (mekanisk prototype)
*TBD*

### Fra Fase 3 (integration + live test)
*TBD*

### Generelle ting at huske ind i tower-design
*TBD*

---

## Genbrug fra pot

Disse moduler/dele kan genbruges direkte:

| Komponent | Genbrugsstatus | Notes |
|---|---|---|
| XIAO ESP32-C6 + ESP-Matter setup | 100% | Samme firmware base |
| Float switch + interlock logic | 100% | Hardware safety pattern |
| Water level capacitive strip | 90% | Bare længere version |
| MOSFET + flyback diode driver | 100% | Samme topologi |
| PD-trigger + buck converter | 100% | Samme strøm-arkitektur |
| OpenSCAD-modules (M3 inserts, gaskets) | 100% | Fra shared/cad-lib/ |
| Plant profile struct | Tilpasses | Bruger ikke moisture, men flow-rate + pH |

## Nye ting tower kræver

- Submersible aquarium-pumpe (vs peristaltisk)
- Større reservoir (2-4 L)
- Net cups + clay pebbles / rockwool
- Plumbing til top-distribution
- Mounting til væg (M5 inserts + tunge skruer)
- (Optional) pH + EC sensorer
- (Optional) LED grow lights + LED driver

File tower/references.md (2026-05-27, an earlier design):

# Tower — References & Inspiration

Links til 3D-printable tower designs, hydroponic guides, og relaterede projekter. Samlet til at lave informerede designvalg når v2 implementeres.

## 3D-printable hydroponic towers

*Tilføj links efterhånden som du finder dem under research-fase.*

- **3D Printed Hydroponic Tower Garden** (oprindelig inspiration nævnt af bruger) — find specifikt design og link
- **Printables.com** — søg "hydroponic tower", "vertical garden"
- **Thingiverse** — søg "vertical hydroponic"
- **GitHub** — søg "hydroponic" + "3d print"

## Hydroponic guides

- **Khan Academy / Wikipedia** for basis principper (NFT vs DWC vs drip)
- **r/hydro** og **r/Hydroponics** subreddits for praktiske erfaringer
- **General Hydroponics** Flora-serien dokumentation

## Akvarie-pumper (stille submersible)

- **Eheim CompactON-serien** — premium ultra-stille
- **Jebao DC-serien** — variabel hastighed, controllable
- **Generic AliExpress 5V/12V mini-pumper** — billig start

## Plante-specifikke guides

- Krydderurter (basilikum, mynte): https://nikolahalshydro.dk/ eller lignende DK-kilder
- Leafy greens hydroponic spacing og næringsstof-krav

## Smart home + Matter

- **Espressif ESP-Matter** dokumentation: https://github.com/espressif/esp-matter
- **Matter Specification 1.3+** (relevant for custom clusters)
- **CSA Connectivity Standards Alliance** ressourcer

## Tilføj løbende

Når du finder et inspirerende design, tilføj her med:
- URL
- Hvad er godt ved det (size, mounting, flow design)
- Hvad er anderledes ved vores krav

Format:

```
- [Project Name](url) — kort beskrivelse
  - Pro: ...
  - Skip: ...
```

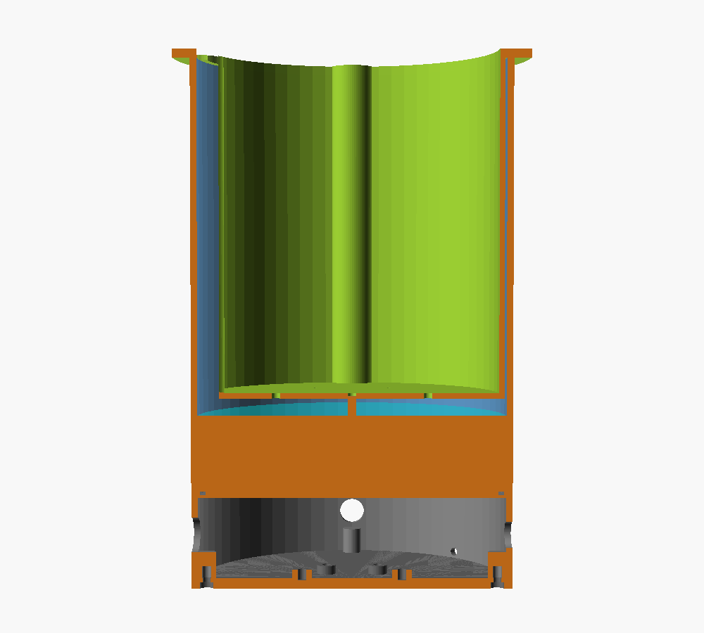
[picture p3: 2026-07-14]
pot/cad/preview/02-full-section.png

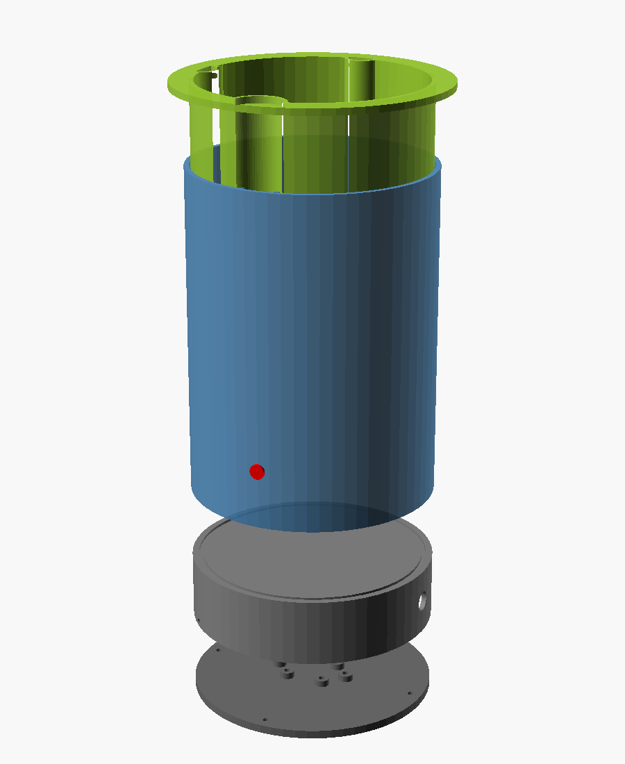
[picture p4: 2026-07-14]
pot/cad/preview/04-exploded.png

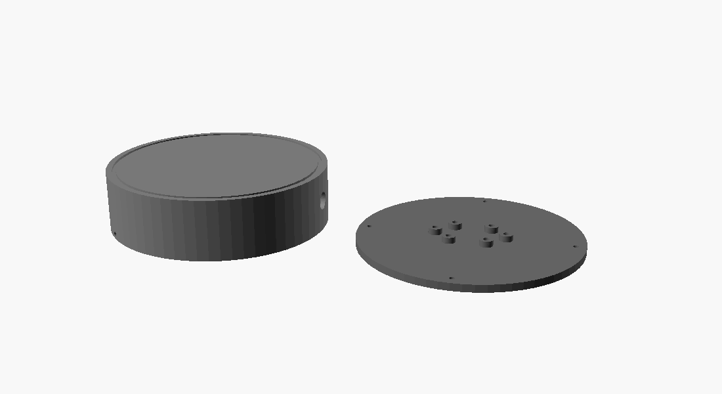
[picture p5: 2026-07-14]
pot/cad/preview/06-ebase-glands.png

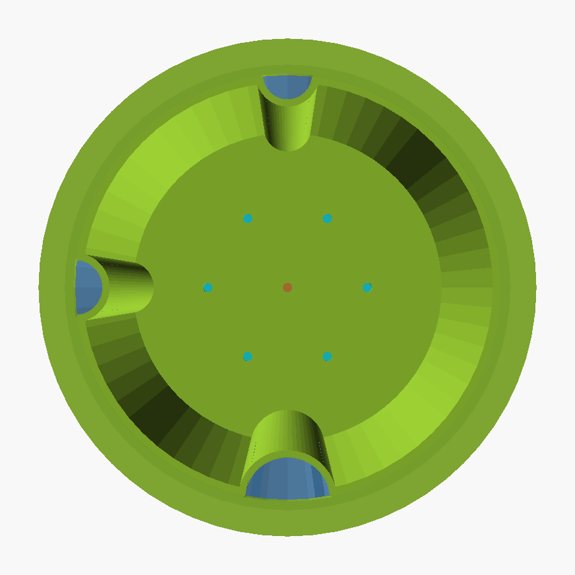
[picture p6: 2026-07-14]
pot/cad/preview/03-flange-top.png

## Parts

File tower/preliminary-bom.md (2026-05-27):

# Foreløbig BOM — Tower (v2)

**Status:** Estimat baseret på pot-erfaring + standard hydroponic-komponenter. Refineres når v1 (pot) er bygget.

## Genbrug fra pot

| Komponent | Antal | Note |
|---|---|---|
| XIAO ESP32-C6 | 1 | Samme MCU |
| MOSFET IRLB8721 + diode + resistor | 1 sæt | Samme driver |
| ZY12PDN PD-trigger | 1 | Eller dedikeret 12V adapter |
| MP1584 buck 12V→5V | 1 | Samme |
| WS2812 LED | 1 | Status |
| Tactile button | 1 | Manual control |
| Float switch | 1 | Low-water cutoff |
| Wires, JST connectors, fasteners | - | Genbrug |

## Tower-specifikke

| # | Komponent | Specifikation | Pris (DKK) | Leverandør | Notes |
|---|---|---|---|---|---|
| 1 | Submersible aquarium pumpe | Eheim CompactON 300 (12V) eller equivalent | ~250 | Akvarium-butik DK / AliExpress | 300 L/h, ultra stille |
| 2 | Net cups 2" (5cm) | Pakke 10-20 stk | ~50 | AliExpress | Standard hydroponic |
| 3 | LECA / clay pebbles | 5 L pose | ~80 | Plantorama, OBI | Substrat |
| 4 | Rockwool starter cubes | 20 stk | ~50 | Hydroponics butik | Til kimplanter |
| 5 | Silikoneslange 8mm ID | 1m, til distribution top | ~30 | AliExpress | Større end pot |
| 6 | T-stykker + L-stykker 8mm | Sæt | ~30 | VVS-butik / AliExpress | Plumbing |
| 7 | Capacitive water level strip (lang) | 10-15cm version | ~120 | DFRobot / AliExpress | Større reservoir = længere strip |
| 8 | Transparent acryl-vindue | 50x150mm, 3mm tykt | ~40 | Lokal byggemarked | Til vand-inspektion |
| 9 | DS18B20 temperatur-sensor (vandtæt) | 1-wire | ~30 | AliExpress | Vandtemperatur monitoring |
| 10 | PETG filament (transparent option) | 1kg | ~180 | 3djake.dk | Til vand-vindue del? eller separat acryl |
| 11 | Plant nutrients | General Hydroponics Flora 3-part 500ml sæt | ~250 | Hydroponic-butik | Til de første måneder |
| 12 | M5 vægmonterings-skruer + plugs | Sæt | ~50 | Byggemarked | Skal bære tower-vægt (~5-8 kg våd) |
| 13 | pH testpapir eller meter (manuel) | Strip pakke | ~30 | Hydroponic-butik | v2 starter manuel |
| 14 | EC meter (manuel, optional) | Handheld | ~150 | AliExpress | Optional v2 |

**Optional grow lights (besluttes senere):**

| # | Komponent | Specifikation | Pris (DKK) | Notes |
|---|---|---|---|---|
| L1 | LED grow strip 12V | Full-spectrum, IP65 | ~200/m | 1-2m per tower |
| L2 | LED driver / MOSFET | 12V, PWM dimming | ~50 | Samme topologi som pump driver |

**Estimeret total (uden optional grow lights, ekskl. genbrug fra pot):** ~1200-1500 DKK

## Notes

- Submersible pumpe er den væsentligste ny-investering. Eheim er high-end (ekstremt stille) men generic 12V kan også prøves først.
- Hydroponic nutrient er en løbende driftsomkostning (~50 DKK/måned ved aktiv brug af 5-7 plant slots).
- Transparent acryl-vindue → integreres i reservoir-print som rektangulær udskæring med klemmer for skift.
- Vægmontering: tower er våd ≈ 5-8 kg når full reservoir. M5-skruer i mur-plugs er minimum; gips-vægge kræver krydsfiner-bagplade først.

## Refineres efter v1

Nye items kan dukke op når v1 er bygget:

- Specifik pumpe-model (med datablade for støj-test)
- Antal net cups (afhænger af besluttet tower-størrelse)
- Grow lights ja/nej baseret på placerings-test
- pH-automatik ja/nej (afhænger af om manuel monitoring føles bøvlet)

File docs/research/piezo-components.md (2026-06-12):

# Research: Piezo-komponenter i GreenThumbs

**Status:** Research-note med konklusioner. Skrevet 2026-06-12.

## Spørgsmålet

Er der noget at hente med piezo-komponenter — strømbesparelse, energi, eller QoL (støj) — i en plantekrukke der står i en bolig?

## 1. Piezo-pumpe (alternativ til peristaltisk)

### Data (Bartels mikropumper, markedets standard)

| Parameter | Bartels BP7 (piezo) | Kamoer KPP (peristaltisk, vores valg) |
|---|---|---|
| Flow (vand) | 0–9 ml/min | ~30 ml/min |
| Effekt | **~50 mW** | ~3.6 W |
| Støj | Nær-lydløs ("low noise level") | Mekanisk klik, hørbart tæt på |
| Levetid | 5000 h | 500–2000 h (slange skiftes) |
| Drive | 250 V peak (kræver driver-modul) | 12V DC direkte (MOSFET) |
| Selvprimende | Ja (op til ~500 mbar) | Ja |
| Pris pumpe | **€57 (~425 DKK)** | ~150 DKK |
| Pris driver | mp-Lowdriver **€67 (~500 DKK)** | ~15 DKK (MOSFET + diode) |
| **Total** | **~925 DKK** | **~165 DKK** |

### Energi-analyse

Pumpe-energi i vores power-budget (Monstera, 50 ml/dag):

- Peristaltisk: 100 sek/dag @ 3.6 W = **0.10 Wh/dag**
- BP7 piezo: 333 sek/dag @ 0.05 W = **0.005 Wh/dag**

Besparelse: 0.095 Wh/dag. Til sammenligning bruger MCU'en 0.15–2.4 Wh/dag afhængig af mode. **Pumpen er allerede den mindste post i budgettet — besparelsen er irrelevant**, selv for batteridrift (forlænger 3S-pack runtime med <2%).

### Støj-analyse

Reel forskel: BP7 er praktisk taget lydløs, peristaltisk har hørbart klik. MEN pumpen kører ~100 sek/dag fordelt på 1-2 events. QoL-gevinsten er marginal for en krukke i stuen — og elektronik-kammeret + pyntepotten dæmper allerede.

**Undtagelse:** Soveværelse-placering hvor selv kortvarig natlig støj er uacceptabel. Her kan firmware i stedet bare time vandingen til dagtimer (gratis løsning).

### Konklusion: FRAVALGT i v1, men mount-forberedt

- 6× pris for marginal gevinst — peristaltisk forbliver v1-valget (ADR 001 står)
- **MEN**: `electronics_base` pump-mount designes med **dual-footprint** så en BP7 + mp-Lowdriver kan eftermonteres uden re-print (premium silent-upgrade)
- **pot-orchid (v2)**: BP7 er reelt interessant dér — soak-tray fyldes langsomt (lav-flow er fint), og præcis dosering + lydløshed passer godt. Noteret i [pot-orchid/design-notes.md](../../pot-orchid/design-notes.md)

## 2. Piezo buzzer (refill-indikator) — VALGT

Passiv piezo buzzer (~5 DKK) drives med PWM fra ESP32 LEDC. Bruges som feedback under reservoir-påfyldning og ved fejl-tilstande. Se [ADR 008](../decisions/008-refill-indicator-piezo.md).

- Strøm: ~10-20 mA kun mens den bipper (sekunder/uge) — negligibelt
- Passiv (PWM-drevet) frem for aktiv: tone-frekvens kan varieres (stigende pitch = stigende vandstand)
- Pin: D2 (GPIO2) — sidste frie GPIO

## 3. Piezo energy harvesting — AFVIST

Idéen: høste energi fra vibrationer (pumpe-drift?) via piezo-elementer.

Realitet: piezo harvesting leverer **µW-niveau** ved kontinuerte vibrationer. Vores pumpe kører 100 sek/dag. Høstet energi: nano-watt-timer. Ikke i nærheden af relevant for noget som helst i systemet. Droppet uden videre analyse.

## Kilder

- [Bartels BP7 hos Darwin Microfluidics](https://darwin-microfluidics.com/products/bartels-bp7-micropump/) (€57, specs)
- [mp-Lowdriver hos Darwin Microfluidics](https://darwin-microfluidics.com/products/mp-lowdriver-controller) (€67)
- [Bartels mp6/BP7 datasheet](https://bartels-mikrotechnik.de/wp-content/uploads/2025/06/Datasheet-mp6-series.pdf)
- [Bartels micropumps oversigt](https://bartels-mikrotechnik.de/micropumps/)

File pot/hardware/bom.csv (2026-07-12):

id | category | component | specification | qty | unit_price_dkk | supplier | part_number | notes
1 | mcu | XIAO ESP32-C6 | Thread+WiFi+BLE+Matter USB-C | 2 | 80 | Mouser DK / Digi-Key / Elektor | 113991138 | Buy 2x for backup
2 | actuator | Peristaltic pump 12V | ~30 ml/min food-grade silicone tubing | 1 | 150 | AliExpress DKL/XP-Pump | KPP-12V | Kamoer or generic equivalent
3 | plumbing | Silicone tubing | 4mm ID x 6mm OD food-grade 2m | 1 | 30 | AliExpress / RS Components |  | Order extra for spares
4 | driver | MOSFET N-channel | IRLB8721 logic-level TO-220 | 5 | 10 | Mouser / Farnell | IRLB8721PBF | Pack of 5 for spares
5 | driver | Schottky diode | 1N5819 flyback | 10 | 3 | Mouser / RS | 1N5819 | Pack of 10
6 | passive | Resistor 10k ohm | 1/4W carbon film for gate pulldown | 10 | 1 | Conrad / local |  | Mixed pack
7 | sensor | Capacitive soil moisture v2.0 | DFRobot-type corrosion resistant analog | 2 | 40 | AliExpress |  | 2x for spare/calibration
8 | sensor | DFRobot Gravity water level | Capacitive strip ~5cm analog out | 1 | 90 | RobotShop EU / Mouser | SEN0204 | Graduated 0-100%
9 | sensor | Float switch mini | Vertical plastic NO 5V | 1 | 25 | AliExpress / Conrad |  | Hardware fail-safe low-water cutoff
10 | sensor | HX711 ADC module | 24-bit ADC for load cell | 1 | 15 | AliExpress / Conrad | HX711 | OPTIONAL - only needed for orchid (DETECT_WEIGHT) profile
11 | sensor | Bar load cell 5kg | Strain gauge bar-type | 1 | 50 | AliExpress / Sparkfun | TAL220-5kg | OPTIONAL - 5kg covers orchid + succulent. Skip for Monstera/large plants (uses moisture only)
12 | power | USB-C PD trigger board | ZY12PDN adjustable 5/9/12/15/20V | 1 | 30 | AliExpress | ZY12PDN | Set to 12V via solder pad
13 | power | Buck converter 12V to 5V | MP1584 adjustable max 3A | 1 | 15 | AliExpress | MP1584 | Set with trimpot
14 | power | USB-C PD adapter | min 30W 12V capable | 1 | 200 | Existing (Apple/Anker) |  | Reuse existing if available
15 | led | WS2812 LED | Single RGB 5V | 1 | 5 | AliExpress / Pimoroni |  | Or 2x regular LED + resistor
16 | input | Tactile button | 6x6mm with cap | 1 | 3 | Conrad |  | Manual pump trigger
17 | connector | JST-XH connector kit | 2/3/4-pin assortment | 1 | 50 | AliExpress | XH-2.54 | Sensor cables
18 | proto | Stripboard | 7x9cm | 1 | 20 | Conrad |  | For v1 soldered prototype
19 | wire | Silicone wire 22AWG | Red/black/yellow ~2m each color | 1 | 40 | AliExpress |  | Flexible for vibration
20 | fastener | M3 brass heat-set inserts | M3x5mm pack 50 | 1 | 50 | AliExpress |  | 3D-print assembly
21 | fastener | M3 bolts | 8/12/16mm stainless assortment | 1 | 50 | Local hardware store |  | Stainless preferred
22 | seal | O-ring or EPDM foam strip | 2mm thickness | 1 | 40 | Local plumbing / AliExpress |  | Electronics base gasket
23 | seal | PG7 cable gland | Waterproof feed-through | 2 | 15 | Conrad / AliExpress | PG7 | USB-C (0deg) + sensor cables (90deg) in ebase side. See ADR 009
23b | seal | PG9 cable gland | Waterproof feed-through 16mm | 1 | 18 | Conrad / AliExpress | PG9 | 2x 6mm hoses (180deg) in ebase side. See ADR 009
24 | filament | PETG filament | 1kg food-neutral white or natural | 1 | 150 | 3djake.dk / Prusa Polymers |  | Water-contact parts
25 | filament | TPU filament 90A | 250g for gaskets | 1 | 120 | 3djake.dk |  | Optional - can substitute silicone
26 | plumbing | Wick cord cotton/nylon | 4mm braided 2m roll | 1 | 20 | AliExpress / craft store |  | OPTIONAL - for wick bottom-watering on African Violet/Peace Lily/Calathea. See ADR 006
27 | sensor | AHT20 temperature+humidity | I2C breakout module 3.3V | 1 | 25 | Adafruit / AliExpress / DFRobot | AHT20 | Standard v1 component - enables VPD-aware dose adjustment + HomeKit room climate. See ADR 007
28 | indicator | Passive piezo buzzer | 12mm disc PWM-driven 3.3V | 1 | 5 | AliExpress / Conrad |  | Refill indicator + error signals on D2. See ADR 008
29 | substrate | LECA clay pebbles | 2-3L bag | 1 | 50 | Plantorama / OBI |  | 2-3cm layer in cup bottom - capillary break against waterlogging. See ADR 009
30 | plumbing | Hose sinker/weight | Stainless or ceramic small weight | 1 | 10 | Aquarium shop / AliExpress |  | Keeps suction hose end at reservoir bottom

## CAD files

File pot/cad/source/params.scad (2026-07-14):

// =============================================================================
// GreenThumbs Plantekrukke — Centrale parametre
// =============================================================================
// Single source of truth for alle dimensioner.
// Ændringer her propagerer til alle .scad-filer der bruger 'use <params.scad>'.
//
// Konvention: alle mål i mm. Vinkler i grader. Tolerances er positive (clearance).
// =============================================================================


// ----------------------------------------------------------------------------
// 1. Plant cup — driver HELE stakkens dimensioner (adaptivt design)
// ----------------------------------------------------------------------------
// ADAPTIV DIAMETER (2026-07): cup-størrelsen driver alle diametre nedstrøms
// (reservoir, electronics base, lid, load cell platform) via et FAST ring_gap.
// Hver størrelse er dermed et MATCHENDE SÆT — reservoir og base re-printes
// per størrelse, til gengæld er gabet altid ens og reservoiret maksimalt.
//
// STACK-GEOMETRI (Variant A): cuppen hænger NEDSÆNKET i reservoiret fra sin
// top-flange, med en vand-zone under cup-bunden. Centrerings-lugs på
// flangens underside holder cuppen præcist i midten.
cup_size = "M";  // "S" | "M" | "L" | "CUSTOM"

// CUSTOM: sæt frit til din pyntepotte. Eksemplet her er tunet til en potte
// med indre mål Ø260×H230: flange Ø254 (3mm luft per side), total stak-
// højde ~229mm (flugter med pottens kant). Kapacitet ~1.35 L. Med
// scalloped-designet (ADR 010) er cuppen Ø230 — 46% mere jord-areal end
// det gamle ring-gab-design gav i samme potte.
custom_cup_diameter = 230;
custom_cup_height   = 145;

cup_diameter = (cup_size == "S") ? 100 :
               (cup_size == "M") ? 140 :
               (cup_size == "L") ? 180 :
               custom_cup_diameter;

cup_height = (cup_size == "S") ? 120 :
             (cup_size == "M") ? 160 :
             (cup_size == "L") ? 200 :
             custom_cup_height;

cup_wall = 2.4;                  // vægtykkelse (6 perimeters @ 0.4mm nozzle)
cup_drain_hole_d = 4;            // diameter på drænhuller i bund
cup_drain_holes_count = 7;       // hex-mønster: 1 center + 6 ring

// Soil sensor slot (snap-fit i indvendig væg)
soil_sensor_w = 12;              // bredde af sensor PCB
soil_sensor_t = 1.8;             // tykkelse af sensor PCB
soil_sensor_slot_depth = 80;     // hvor langt ned sensor stikkes


// ----------------------------------------------------------------------------
// 2. Reservoir (Variant A: cup hænger nedsænket) — SCALLOPED CUP (ADR 010)
// ----------------------------------------------------------------------------
// Cuppen fylder næsten HELE reservoir-åbningen (kun 1mm kant-clearance).
// Ring-gabet er erstattet af 3 lodrette SERVICE-KANALER — konkave cirkel-
// udskæringer i cup-kanten med hver sin funktion (kabler/slanger/refill).
// Det maksimerer jord-arealet (~40% af tværsnittet var før spildt gab) og
// kanalerne selv låser orienteringen (se channel_* nedenfor).

cup_clearance = 1;               // kant-spillerum cup ↔ reservoir-indervæg
reservoir_wall = 3;              // tykkere end cup (vandtryk + stabilitet)
reservoir_inner_d = cup_diameter + 2 * cup_clearance;   // ADAPTIV
reservoir_outer_d = reservoir_inner_d + 2 * reservoir_wall;

// SERVICE-KANALER: cirkler centreret PÅ cup-omkredsen, skåret lodret ned
// gennem cup-krop + flange. Forskellige diametre → strip-ribberne på
// reservoir-væggen (ved 270°) kan KUN passere gennem den brede refill-
// kanal → cuppen kan kun sænkes ned i ÉN orientering. Centrering klares
// af den tætte kant-clearance.
channel_cable_angle  = 90;       // sensor-kabler (soil/strip/float)
channel_cable_d      = 16;
channel_hose_angle   = 180;      // 2× Ø6 slanger (suge + tryk)
channel_hose_d       = 18;
channel_refill_angle = 270;      // påfyldning + water-strip + ribber
channel_refill_d     = 28;       // ≥ strip-ribbe-spænd (~26mm) → unik lås

// Top-ring til plant cup (defineres FØR reservoir_height-formlen —
// OpenSCAD tillader ikke forward references)
top_ring_width = 8;              // bredden af flange-overlap
top_ring_height = 4;

// Vand-zone under cup-bunden — vandet lever her (+ i ringen omkring cup)
water_zone_h = 40;

// Højde: cup hænger fra flangen på top-rim; cup-bund ender water_zone_h
// over reservoirets indre bund
reservoir_height = (cup_height - top_ring_height) + water_zone_h + reservoir_wall;

// OVERFLOW (ADR 009): fysisk beskyttelse mod overfyldning. Hul i
// reservoir-væggen overflow_margin under cup-bunden — fylder man forbi,
// løber overskuddet ud i pyntepotten i stedet for op i jorden.
// Placeret ved 270° (under refill-åbningen) så overløb ses ved påfyldning.
overflow_margin = 8;             // afstand fra cup-bund ned til overflow-niveau
overflow_hole_d = 5;
overflow_z = reservoir_wall + water_zone_h - overflow_margin;

// Beregnet vandkapacitet ved max fill-line (= overflow-niveau):
reservoir_capacity_ml = PI * pow(reservoir_inner_d / 2, 2)
                        * (water_zone_h - overflow_margin) / 1000;

// Cup-flange: dækker hele reservoir-toppen (matchende sæt per størrelse).
// Kanalerne fortsætter op gennem flangen (klippet til reservoir-åbningen
// så påfyldt vand kun kan lande I reservoiret).
flange_outer_d = reservoir_outer_d + 2 * top_ring_width;

// ============================================================================
// ZERO-PENETRATION PRINCIP (ADR 009): INGEN huller under vandlinjen.
// Alle slanger + kabler ruter: op gennem SERVICE-KANALERNE i cup-kanten
// (ADR 010) → ned UDVENDIGT langs reservoiret → ind i ebase via side-glands.
//
// Vinkel-allokering (set oppefra, konsistent på tværs af alle dele):
//    0°: USB-C gland (ebase)
//   45°: drænhul (ebase, fri af bosses)
//   90°: KABEL-KANAL (cup) + float-klips (bund) + kabel-gland (ebase)
//  180°: SLANGE-KANAL (cup) + trykslange-hul i kanal-væg + PG9-gland (ebase)
//  270°: REFILL-KANAL (cup) + water-strip ribber (væg) + overflow-hul (væg)
//
// Orientering: strip-ribberne (spænd ~26mm) passerer kun refill-kanalen
// (Ø28) — kabel/slange-kanalerne (Ø16/18) er for smalle → kun ÉN rotation
// er fysisk mulig. Centrering: 1mm kant-clearance.
// ============================================================================

// Water level strip — holdes af to lodrette guide-ribber på indervæggen
// ved 270° (inde i refill-kanalen — strippen er vandtæt og måler jo netop
// vand, så påfyldnings-strømmen forbi den er uproblematisk).
// (IKKE en fræset slot: det skar gennem væggen = lækage. Audit-fix 2.)
waterlevel_strip_w = 18;
waterlevel_strip_t = 2;
waterlevel_strip_h = 50;         // dækker vand-zonen (0-40mm) + margin
strip_rib_w = 3;                 // ribbe-bredde (tangentielt)
strip_rib_t = 3;                 // ribbe-dybde (radialt, ind i kanal-rummet)

// Float switch — sidder i en print-integreret klips-ring i bunden.
// Kablet går op gennem vandet og op ad kabel-kanalen ved 90°.
float_switch_d = 16;             // typisk vertical float switch
float_switch_x = 30;             // offset fra center (under cuppen)
float_clip_h = 10;               // klips-ring højde
float_clip_wall = 2;

// Trykslangens dyse-hul i cup-væggen (i slange-kanalens flade, nær toppen)
pump_port_d = 7;                 // 4mm slange + tolerance


// ----------------------------------------------------------------------------
// 3. Electronics base (vandtæt kammer)
// ----------------------------------------------------------------------------
ebase_outer_d = reservoir_outer_d;  // matcher reservoir for stack-look
ebase_height = 40;                  // højde af elektronik-kammer
ebase_wall = 3;                     // tykkere walls for stabilitet
ebase_lid_height = 5;               // tykkelse af snap-on låg

// O-ring/gasket groove på top (forbinder med reservoir bund)
gasket_groove_w = 2.5;              // for 2mm O-ring
gasket_groove_d = 1.6;
gasket_groove_offset = 4;           // fra ydre kant

// Cable glands i ebase-siden (zero-penetration: alt kommer ind fra siden,
// ebase-toppen er nu HELT lukket). Vinkler matcher flange-åbningerne lodret:
//   0° = USB-C (PG7), 90° = sensor-kabler (PG7), 180° = slanger (PG9/grommet)
gland_hole_d = 12;                  // PG7 = 12mm hul (USB-C + kabler)
hose_gland_d = 16;                  // PG9 = 16mm hul (2× Ø6 slanger)
gland_angles = [0, 90];             // PG7-positioner
hose_gland_angle = 180;

// Drænhul (fail-safe ved lækage). AUDIT-FIX: 3→4mm (hurtigere afløb ved
// pumpe-lækage) + roteres 45° i ebase så det ikke skærer mounting bosses.
drain_hole_d = 4;
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

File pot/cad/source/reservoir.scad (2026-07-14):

// =============================================================================
// Reservoir — Vand-beholder som plant cup hænger nedsænket i (Variant A)
// =============================================================================
// ZERO-PENETRATION (ADR 009): reservoiret har INGEN gennemføringer under
// vandlinjen — bunden og væggen under overflow-niveau er 100% tætte.
// Eneste hul er OVERFLOW-hullet (over max-fill, det er selve pointen).
// Slanger og kabler ruter gennem ring-gabet og cup-flangens åbninger.
//
// Features (vinkler jf. params.scad allokering / ADR 010 scalloped cup):
//   90°: float switch klips-ring i bunden (kabel op ad cup'ens kabel-kanal)
//  270°: to lodrette guide-ribber til water level strip — de stikker ind i
//        cup'ens brede REFILL-KANAL og fungerer samtidig som rotations-lås
//        (ribbe-spændet passer kun i den kanal) — plus overflow-hul i
//        væggen, 8mm under cup-bund-niveau
//
// STACK VARIANT A: høj cylinder hvor cuppen hænger fra top-rimmen via sin
// flange. Vandet lever i zonen UNDER cup-bunden. Højde og kapacitet
// beregnes i params.scad (M-cup: ~199mm, ~815 ml til overflow-niveau).
//
// PRINT: PETG. 3 perimeters minimum. 100% bund. Print upright med brim.
// Høj print (~200mm) — Prusa XL klarer det fint; brug draft shield ved træk.
// =============================================================================

include <params.scad>

module reservoir() {
    union() {
        difference() {
            // ─── Solid outer body ───────────────────────────────────────────
            cylinder(d = reservoir_outer_d, h = reservoir_height);

            // Hovedhulrum (vand + plads til nedsænket cup)
            translate([0, 0, reservoir_wall])
                cylinder(d = reservoir_inner_d,
                         h = reservoir_height + 1);

            // Overflow-hul ved 270° — eneste hul, og det sidder BEVIDST
            // ved max-fill niveau (8mm under cup-bund). Overløb drypper
            // ud i pyntepotten, synligt fra refill-åbningen ovenover.
            rotate([0, 0, 270])
                translate([0, 0, overflow_z])
                    rotate([0, 90, 0])
                        cylinder(d = overflow_hole_d,
                                 h = reservoir_outer_d / 2 + 2);
        }

        // ─── Additive features (ingen af dem gennembryder væggen) ───────────

        // Water level strip guide-ribber ved 270° — inde i cup'ens
        // refill-kanal. Strippen skubbes ned mellem ribberne og hviler
        // mod indervæggen. Ribberne går i FULD højde op til rimmen:
        // de fungerer samtidig som rotations-lås (spændet ~26mm passerer
        // kun cup'ens Ø28 refill-kanal — de smallere kanaler blokerer).
        for (side = [-1, 1]) {
            rotate([0, 0, channel_refill_angle])
                translate([reservoir_inner_d / 2 - strip_rib_t,
                           side * (waterlevel_strip_w / 2 + print_tolerance
                                   + strip_rib_w / 2) - strip_rib_w / 2,
                           reservoir_wall])
                    cube([strip_rib_t, strip_rib_w,
                          reservoir_height - reservoir_wall]);
        }

        // Float switch klips-ring i bunden ved 90° (åben ring, floaten
        // presses ned i). Kablet føres langs bunden ud til ring-gabet.
        rotate([0, 0, 90])
            translate([float_switch_x, 0, reservoir_wall])
                difference() {
                    cylinder(d = float_switch_d + 2 * float_clip_wall
                                 + print_tolerance,
                             h = float_clip_h);
                    translate([0, 0, -0.5])
                        cylinder(d = float_switch_d + print_tolerance,
                                 h = float_clip_h + 1);
                    // Kabel-udgang i klips-ringen (mod ring-gabet, +X lokal)
                    translate([0, -3, -0.5])
                        cube([float_switch_d, 6, float_clip_h + 1]);
                }

        // (Rim-tapper fjernet — ADR 010: orientering låses af strip-
        //  ribberne i refill-kanalen, centrering af 1mm kant-clearance.)
    }
}

// Render reservoir når filen åbnes direkte
reservoir();

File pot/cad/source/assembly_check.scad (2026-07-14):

// =============================================================================
// Assembly Check — visualisering af hele stakken (Variant A, zero-penetration)
// =============================================================================
// Genbrugelig preview-fil med flere view-modes. Vælg view med -D:
//
//   openscad -D 'view="section"' -o out.png assembly_check.scad
//
// Views:
//   "iso"       hel samling udefra, ¾-vinkel (default)
//   "section"   halv-snit forfra — viser vand-zone, ring-gab, nedsænket cup
//   "top"       set lige oppefra — flangens åbninger (slange/kabel/refill)
//   "exploded"  eksploderet stack — alle dele adskilt lodret
//   "reservoir" reservoir alene, skråt ned i — ribber, float-klips, overflow
//   "ebase"     electronics base + lid udefra — glands og drain
//
// Farver: grøn=cup, blå=reservoir, cyan=vand, grå=ebase, mørkegrå=lid,
//         rød=overflow-markør, brun=wick
// =============================================================================

include <params.scad>
use <reservoir.scad>
use <plant_cup.scad>
use <electronics_base.scad>

view = "iso";  // override med -D

// ─── Placeringshøjder ────────────────────────────────────────────────────────
z_lid   = 0;
z_ebase = ebase_lid_height;
z_res   = z_ebase + ebase_height;
// -0.05: marginal interpenetration mellem flange og rim, så STL-eksport af
// visualiseringen ikke får coincident faces (ren PNG-preview er upåvirket)
z_cup   = z_res + reservoir_height - (cup_height - top_ring_height) - 0.05;

// ─── Helpers ─────────────────────────────────────────────────────────────────
module half() {
    difference() {
        children();
        translate([-300, -600, -50]) cube([600, 600, 600]);
    }
}

module stack(explode = 0) {
    // Lid (mørkegrå) — pump-mount bosses opad
    color("dimgray")
        translate([0, 0, z_lid])
            electronics_base_lid();

    // Electronics base (grå)
    color("gray")
        translate([0, 0, z_ebase + explode])
            electronics_base();

    // Reservoir (blå)
    color("steelblue", 0.9)
        translate([0, 0, z_res + 2 * explode])
            reservoir();

    // Vand (cyan) — op til overflow-niveau (max-fill)
    color("cyan", 0.45)
        translate([0, 0, z_res + 2 * explode + reservoir_wall])
            cylinder(d = reservoir_inner_d,
                     h = overflow_z - reservoir_wall);

    // Overflow-markør (rød skive udenpå væggen ved 270°)
    color("red")
        translate([0, 0, z_res + 2 * explode + overflow_z])
            rotate([0, 0, 270])
                translate([reservoir_outer_d / 2, 0, 0])
                    rotate([0, 90, 0])
                        cylinder(d = overflow_hole_d + 4, h = 1.5);

    // Plant cup (grøn)
    color("yellowgreen", 0.95)
        translate([0, 0, z_cup + 3 * explode])
            plant_cup();

    // Wick (brun) — fra cup-bund ned i vandet
    color("peru")
        translate([0, 0, z_res + 2 * explode + reservoir_wall + 1])
            cylinder(d = 4, h = water_zone_h + 2 * explode);
}

// ─── View dispatch ───────────────────────────────────────────────────────────
if (view == "iso") {
    stack();
} else if (view == "section") {
    half() stack();
} else if (view == "top") {
    stack();
} else if (view == "exploded") {
    stack(explode = 45);
} else if (view == "reservoir") {
    // Halv-snit så indvendige features ses: strip-ribber (0°),
    // float-klips (90°), overflow-hul (270°), index-tap (315°).
    // +100° rotation lægger ribber, overflow og tap i den synlige halvdel;
    // float-klipsen (lille radius) ligger tæt nok på snitplanet til at ses.
    half() rotate([0, 0, 100]) color("steelblue") reservoir();
} else if (view == "ebase") {
    color("gray") electronics_base();
    translate([ebase_outer_d + 25, 0, 0])
        color("dimgray") electronics_base_lid();
} else {
    echo("Ukendt view — brug iso|section|top|exploded|reservoir|ebase");
}

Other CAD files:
pot/cad/source/electronics_base.scad
pot/cad/source/load_cell_mount.scad
pot/cad/source/plant_cup.scad
pot/cad/source/stack_variants_preview.scad

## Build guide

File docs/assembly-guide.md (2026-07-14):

# Assembly Guide — Plantekrukke v1

**Status:** Skelet — udfyldes med fotos under Fase 2/3 (mekanisk prototype + integration).

## Del-oversigt

| Del | Print-fil | Materiale | Note |
|---|---|---|---|
| Plant cup (S/M/L) | `plant_cup.scad` | PETG | Vælg størrelse efter plante |
| Reservoir | `reservoir.scad` | PETG | Højde følger cup-størrelse |
| Electronics base | `electronics_base.scad` | PETG | 40% infill |
| Electronics lid | `electronics_base.scad` (lid-modul) | PETG/PLA | Pump-mount bosses på top |
| Load cell mount ×2 | `load_cell_mount.scad` (render_mode="plate") | PLA/PETG | KUN til orkide/vægt-config |

## Vinkel-orientering (vigtig!)

Alle dele er vinkel-indekserede (se [ADR 009](decisions/009-zero-penetration-overflow.md)
og [ADR 010](decisions/010-scalloped-cup-channels.md)). Cuppen har 3
service-kanaler i kanten; reservoir-væggens strip-ribber passer kun i den
brede refill-kanal, så cuppen kan kun sænkes ned i én rotation:

- **0°**: USB-C gland i ebase
- **90°**: KABEL-KANAL i cuppen, float-klips i bunden, kabel-gland i ebase
- **180°**: SLANGE-KANAL i cuppen (dyse-hul øverst i kanal-fladen), PG9-gland i ebase
- **270°**: REFILL-KANAL i cuppen, water-strip mellem guide-ribberne på
  væggen, overflow-hul i reservoir-væggen under

## Samling (rækkefølge)

1. **Electronics base**: montér XIAO, MOSFET-board, buck, PD-trigger. Pumpen skrues på lid'ets bosses (Kamoer på 46mm-hullerne / BP7 på 24mm-kvadratet). Skru lid på med 4× M3.
2. **Glands**: PG7 ved 0° (USB-C) og 90° (sensor-kabler), PG9 ved 180° (slanger).
3. **Reservoir** placeres oven på ebase med EPDM/O-ring i gasket-grooven.
4. **Float switch** klipses i ringen ved 90°; kablet føres op ad kabel-kanalen.
5. **Water-strip** skubbes ned mellem guide-ribberne ved 270° (i refill-kanalen); kabel op ad samme kanal og over i kabel-kanalen via flangen.
6. **Sugeslange**: én ende med lille vægt/sinker ned i vand-zonen (gennem slange-kanalen), anden ende op ad kanalen → udvendigt ned → PG9 → pumpe-indgang.
7. **Trykslange**: fra pumpe-udgang → PG9 → op udvendigt → ned i slange-kanalen → ind i dyse-hullet øverst i kanal-fladen.
8. **Kabler** (soil, strip, float): op ad kabel-kanalen (90°) → ned udvendigt → PG7 ved 90°.

## LECA-lag (VIGTIGT — beskytter mod vandlogging)

Læg **2-3 cm LECA-kugler (lerkugler) i bunden af plant cup** før jorden:

- Bryder kapillær kontakt hvis vandstanden kortvarigt når cup-bunden
- Forbedrer drænage fra top-vanding
- **Undtagelse**: wick-planter (African Violet m.fl.) — her skal wick'en gå
  gennem LECA-laget og godt op i selve jorden, ellers når kapillær-virkningen
  ikke rødderne

## Plantning

1. Træd wick gennem center-drænhullet hvis planten skal bottom-vandes (se [ADR 006](decisions/006-bottom-watering-strategies.md))
2. LECA-lag, derefter jord + plante
3. Stik soil-sensoren i jorden (elektronik-enden over jordniveau), kabel via flange-slidsen
4. Sænk cuppen i reservoiret — **drej til refill-kanalen (den brede) glider
   ned over strip-ribberne** (der er kun én orientering der passer)
5. Fyld vand gennem refill-åbningen (270°) til buzzeren dobbelt-bipper
   — eller til der drypper fra overflow-hullet (så er den HELT fuld; stop)

## Kalibrering

Følg [calibration.md](calibration.md) — bemærk at water-strip'ens 100%-punkt
(`adc_full`) måles ved **overflow-niveau** (fyld til det drypper, vent til
dryppet stopper, kalibrér).

## Fotos

*TODO Fase 2/3: indsæt fotos af hver samlings-trin.*

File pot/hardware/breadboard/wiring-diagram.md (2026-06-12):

# Wiring Diagram — Plantekrukke v1 Breadboard Prototype

**Single source of truth** for pin-mapping mellem firmware og hardware. Hvis du ændrer pin-assignment her, opdater også `pot/firmware/src/main.cpp` PIN_* konstanter.

## XIAO ESP32-C6 pinout reference

```
                ┌─────────────┐
        TX  D6 ─┤             ├─ D7  RX
        SDA D4 ─┤             ├─ D5  SCL
            D8 ─┤             ├─ D3
            D9 ─┤             ├─ D10
            5V ─┤             ├─ 3V3
           GND ─┤             ├─ D2  (ADC2)
            D0 ─┤             ├─ D1  (ADC1)
          (ADC0)              
                │   USB-C     │
                └─────────────┘
```

ADC-capable: D0 (ADC1_CH0), D1 (ADC1_CH1), D2 (ADC1_CH2)
Total brugbare GPIO: 11

## Pin allocation (v1 med AHT20)

| XIAO pin | GPIO | Function | Tilslutning | Notes |
|---|---|---|---|---|
| D0 | GPIO0 | ADC | Soil moisture sensor (AOUT) | Bruges af profil-system, kalibreres dry/wet |
| D1 | GPIO1 | ADC | Water level strip (AOUT) | DFRobot SEN0204 analog |
| D2 | GPIO2 | GPIO PWM | **Piezo buzzer** (passiv, LEDC-drevet) | Refill-indikator + fejl-signaler. Se ADR 008 |
| D3 | GPIO21 | GPIO ISR | Float switch | Internal pull-up; LOW = vand tomt |
| D4 | GPIO22 | **I2C SDA** | **AHT20 SDA** | Standard I2C bus til environmental sensor |
| D5 | GPIO23 | **I2C SCL** | **AHT20 SCL** | Standard I2C bus |
| D6 | GPIO16 | GPIO | **HX711 SCK** (clock) | Flyttet fra UART TX — USB-CDC console nu i brug |
| D7 | GPIO17 | GPIO | **HX711 DOUT** (data) | Flyttet fra UART RX |
| D8 | GPIO19 | GPIO | WS2812 LED data | Status indicator |
| D9 | GPIO20 | GPIO | Manuel knap | Internal pull-up; LOW = pressed |
| D10 | GPIO18 | GPIO PWM | Pump MOSFET gate | 0 = pump off, HIGH = pump on. PWM-capable for hastighedskontrol |

**Pin-budget er nu FULDT allokeret** (alle 11 GPIO i brug). Næste sensor/aktuator kræver I2C-device (AHT20-bussen kan deles — fx en I2C GPIO-expander eller DS18B20 via I2C-bridge).

> **Vigtigt ændring fra tidligere wiring:** AHT20 environmental sensor blev tilføjet som standard v1-komponent (se [ADR 007](../../../docs/decisions/007-env-sensor-aht20.md)). Det krævede:
> - HX711 flyttet fra D4/D5 til D6/D7 (frigør I2C-bussen for AHT20)
> - UART TX/RX (D6/D7) er ikke længere i brug; ESP-IDF console er routet til **USB-CDC** via `CONFIG_ESP_CONSOLE_USB_SERIAL_JTAG=y` i `sdkconfig.defaults`
> - Serial monitor virker stadig — bare via samme USB-C kabel som programmering. På macOS: `/dev/cu.usbmodem*`

## Power rails

```
USB-C 5V/PD ──→ ZY12PDN ──┬──→ 12V rail ──→ Pumpe (via MOSFET drain)
                          │
                          └──→ MP1584 ──→ 5V rail ──→ XIAO 5V pin
                                                    └──→ Sensorer (3.3V via XIAO 3V3-pin)

GND rail: alt deler GND fra ZY12PDN GND-pin.
```

**Vigtig**: Sensorer kører på 3.3V (fra XIAO 3V3-pin), IKKE 5V. Soil sensor, water-level strip, HX711, og AHT20 er alle 3.3V-tolerante (eller har on-board regulator).

## Komplet wiring

```
USB-C Adapter (≥30W PD)
    │ USB-C cable
    ↓
┌──────────────┐
│  ZY12PDN     │
│  PD trigger  │
│  (set 12V)   │
└──────────────┘
    │ 12V output     ┌──────────────┐
    ├────────────────┤   MP1584     │
    │                │   buck conv  │── 5V ──→ XIAO 5V pin
    │                │   12V→5V     │── GND ─→ XIAO GND
    │                └──────────────┘
    │
    │ 12V                                   ┌──── MOSFET drain
    └──────────────────────────────────────→│
                                            │  IRLB8721
    GPIO D10 ──[ 10kΩ pulldown to GND ]─────│  N-channel
                                            │
                                  source ───┴──── GND
                                            │
                                            │ Pump terminal +
                                            ↓
                                       ┌─────────┐
                                       │ Pump 12V│
                                       │  Kamoer │
                                       └─────────┘
                                            │ Pump terminal -
                                            ↓
                                           GND
                                       (+ 1N5819 diode i parallel,
                                        cathode mod +12V, anode mod GND-side)

XIAO ESP32-C6
  3V3 ──→ Soil sensor VCC
        → Water level strip VCC
        → HX711 VCC
        → AHT20 VCC
        → Float switch (en side; anden side til GPIO)

  GND ──→ All sensor GNDs (shared ground)

  D0 (ADC) ──→ Soil sensor AOUT
  D1 (ADC) ──→ Water level strip AOUT
  D3 ──→ Float switch (via 10kΩ pull-up til 3.3V, switch til GND when wet)
  D4 (SDA) ──→ AHT20 SDA   ←─[ 4.7kΩ pull-up til 3.3V ]─
  D5 (SCL) ──→ AHT20 SCL   ←─[ 4.7kΩ pull-up til 3.3V ]─
  D6 ──→ HX711 SCK
  D7 ──→ HX711 DOUT
  D8 ──→ WS2812 DIN
  D9 ──→ Manual button (internal pull-up, switch til GND)
  D10 ──→ MOSFET gate (via 10kΩ pulldown til GND)
```

## AHT20 (environmental sensor) detaljer

```
AHT20 modul (Adafruit 4566 eller AliExpress generic)
  ┌─────────────┐
  │ VCC ──→ 3.3V│
  │ GND ──→ GND │
  │ SDA ──→ D4  │ (med 4.7kΩ pull-up til 3.3V)
  │ SCL ──→ D5  │ (med 4.7kΩ pull-up til 3.3V)
  └─────────────┘
```

**I2C address:** 0x38 (fast)
**Pull-ups:** De fleste AHT20 breakout-boards har integrerede 10kΩ pull-ups på SDA/SCL. Hvis dit board IKKE har dem, tilføj 4.7kΩ resistorer til 3.3V på hver linje.
**Placering:** Mount AHT20 et sted i electronics base hvor luften kan cirkulere — IKKE direkte over MP1584 buck-converter (varm) eller ESP32 (varm). Helst ved siden af en cable gland så ekstern luft kan nå sensoren.

## HX711 detaljer

```
HX711 modul
  ┌─────────────┐
  │ VCC ──→ 3.3V│
  │ GND ──→ GND │
  │ DT  ──→ D7  │ (DOUT — data line, ESP læser herfra)
  │ SCK ──→ D6  │ (clock — ESP styrer)
  │             │
  │ E+ ──→ Load cell rød   │
  │ E- ──→ Load cell sort  │
  │ A+ ──→ Load cell hvid  │ (eller grøn afhængig af model)
  │ A- ──→ Load cell grøn  │ (eller hvid)
  └─────────────┘
```

Hvis load cell-aflæsning er negativ ved positiv vægt: swap A+ og A- ledninger.

## Float switch wiring

Float switch er normalt NO (Normally Open) når op (vand tilstede), CLOSED når nede (vand tom).

```
Float switch wire 1 ──→ GPIO D3
Float switch wire 2 ──→ GND
D3 har INTERNAL pull-up enabled in firmware
→ Switch closed (vand tom) = GPIO LOW = ISR triggered
→ Switch open (vand tilstede) = GPIO HIGH = OK
```

## Til prototype-fase

For v1 breadboard:
1. XIAO på 0.1" header → breadboard
2. MOSFET, MP1584, ZY12PDN på samme breadboard
3. AHT20 breakout board direkte på breadboard (lille)
4. Sensorer via JST-XH connectors (laver pigtail kabel: JST → male jumper pins)
5. Pumpe direkte til breadboard 12V rail med skrue-terminaler eller solid wire

For v2 custom PCB (senere): KiCad schematic baseret på dette diagram. Allerede planlagt i `pot/hardware/schematic/`.

## Console / debug

Console output (`ESP_LOGI`, printf, etc.) går via **USB-CDC** (samme USB-C kabel som programmering). På macOS:
```bash
# Find serial port
ls /dev/cu.usbmodem*

# Open monitor
pio device monitor
```

Hvis du af en eller anden grund vil bruge UART i stedet (fx ekstern USB-UART konverter): sæt `CONFIG_ESP_CONSOLE_UART_DEFAULT=y` i sdkconfig.defaults og flyt HX711 til andre pins (men D2 og D9 er allerede taget — så det kræver kompromis).

## ESD/safety notes

- Ingen 230V AC i selve pot-elektronikken — USB-C adapter håndterer alt mains-side.
- Pumpe 12V og GPIO 3.3V er på samme GND men galvanisk uadskilte. MOSFET-switching kan injicere støj — placér 100µF elko ved MP1584 input/output, og 10µF tæt på XIAO 5V pin.
- Sensor-kabler op til ~50cm bør være shielded eller twisted pair for at undgå ADC-støj fra pumpe-switching.
- AHT20 I2C-kabler holdes korte (<20cm); ellers tilføj stærkere pull-ups (2.2kΩ).

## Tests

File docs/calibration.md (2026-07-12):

# Kalibreringsprocedure

Dokumenteret procedure for at kalibrere alle sensorer og pumpe på en samlet krukke. Udføres første gang ved opsætning, og periodisk hver 3-6 måned for sensor-drift.

## 1. Pumpe-kalibrering (ml/sek konstant)

**Formål**: Konverter pump-aktiveringstid til præcis volumen.

1. Saml elektronik + pumpe + slange. Sæt slange-udløb over et målebæger.
2. Fyld reservoir med vand.
3. Via UART serial monitor eller HomeKit-knap: trig pumpe i præcis 10.0 sekunder.
4. Vej output (1 gram vand = 1 ml).
5. Beregn `pump_ml_per_sec = output_ml / 10.0`.
6. Gem i NVS via firmware-kommandoen `cal pump <ml_per_sec>`.
7. **Verifikation**: kør pumpe i 5 sek og 20 sek, mål output. Forventet inden for ±5%.

Typisk værdi for Kamoer KPP @ 12V: ~0.5 ml/sek (30 ml/min).

## 2. Soil moisture sensor (kapacitiv)

**Formål**: Sæt `adc_dry` (luft) og `adc_wet` (våd jord) referencer per sensor-eksemplar.

1. Hold sensoren i åbn luft (ikke rør elektronikken). Vent 5 sek for stabilisering.
2. Læs ADC-værdi fra UART (eller `sensor read soil` kommando). Notér som `adc_dry`.
3. Dyp sensoren i et glas vand op til markeringslinjen (IKKE elektronikken!). Vent 5 sek.
4. Læs ADC-værdi. Notér som `adc_wet`.
5. Gem begge i NVS via `cal soil <adc_dry> <adc_wet>`.

Typiske værdier (DFRobot kapacitiv v2.0 @ 3.3V):
- `adc_dry` ≈ 3000 (højere = tørrere)
- `adc_wet` ≈ 1200

Procent beregnes som: `pct = 100 * (adc_dry - reading) / (adc_dry - adc_wet)`, clampet til [0, 100].

## 3. Water level strip (kapacitiv)

**Formål**: Sæt `adc_empty` og `adc_full` for vandniveau-strip.

1. Tom reservoir helt (eller fjern strippen og hold den tør).
2. Læs ADC-værdi. Notér som `adc_empty`.
3. Fyld reservoir til **overflow-niveau**: hæld til det begynder at dryppe
   fra overflow-hullet (270°), stop, og vent til dryppet er ophørt. Det er
   det fysisk entydige 100%-punkt (ADR 009).
4. Læs ADC-værdi. Notér som `adc_full`.
5. Gem via `cal water <adc_empty> <adc_full>`.

Typiske værdier (DFRobot SEN0204): `adc_empty` ≈ 0, `adc_full` ≈ 3000.

## 4. Float switch (binær)

**Formål**: Verificer at low-water cut-off virker.

1. Sæt float switch i reservoir-bund. Reservoir tom.
2. Verificer at GPIO læser **LOW** (= "vand tomt"). Hvis HIGH: tjek polaritet på switch (NO vs NC).
3. Fyld reservoir langsomt. Når vandstand når ~1cm over switch-toppen, skal GPIO skifte til **HIGH**.
4. Verificer via firmware-log eller HomeKit Leak Detector-cluster.

Ingen NVS-kalibrering nødvendig — float er binær.

## 5. HX711 load cell

**Formål**: Sæt scale-faktor og tare-baseline.

1. Sæt hele krukken (samlet) på load cell platform — tom (ingen plante, ingen vand).
2. Læs HX711 rå-værdi. Notér som `raw_zero`.
3. Sæt en standard-vægt på krukken (fx 500g certificeret kalibreringslod).
4. Læs rå-værdi. Notér som `raw_500g`.
5. Beregn `scale_factor = 500.0 / (raw_500g - raw_zero)` (gram per LSB).
6. Gem i NVS via `cal weight <raw_zero> <scale_factor>`.
7. **Verifikation**: brug 100g lod, forvent aflæsning 100g ±2g.

## 6. Plant tare (per plante, ikke per sensor)

**Formål**: Sæt `weight_baseline_g` for den specifikke plante.

1. Plant planten, fyld reservoir, kør første vanding manuelt så jorden er optimalt fugtet.
2. Vent 30 min så vand er fordelt og dryp er stoppet.
3. Tryk på "Tare"-knap (fysisk knap på krukken, eller HomeKit-knap).
4. Firmware gemmer aktuel HX711-vægt som `weight_baseline_g` for aktiv profil.
5. Fra nu af måles vand-behov som vægt-fald fra denne baseline.

**Hvornår re-tare**: Hver gang du omplanter, beskærer betydeligt, eller skifter potte-substrat.

## Genkalibrerings-skema

| Komponent | Frekvens | Symptomer der trigger re-kalibrering |
|---|---|---|
| Pumpe ml/sek | Hver 6. måned | Aflejringer i slangen ændrer flow-rate |
| Soil sensor dry/wet | Hver 6. måned | Aflæsninger drifter, jord ser ikke ud som beregnet |
| Water level | Hver 12. måned | Stripper kalk-belægning ændrer kapacitans |
| Float switch | Visuel inspektion 6. måned | Float kan kile sig fast af biofilm |
| HX711 zero | Ved synlig drift | Temperaturskift ved sæson-skifte |
| Plant tare | Ved omplantning | Ny baseline efter genplantning |

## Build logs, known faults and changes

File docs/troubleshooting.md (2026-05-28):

# Troubleshooting

Common issues og hvordan du diagnostiserer dem. Opdateres løbende under prototyping.

## Pumpen vil ikke køre

1. **Tjek float switch**: hvis reservoir er tom → safety-interlock blokerer pumpe. Fyld vand op.
2. **Tjek HomeKit-status**: er manuel-pump-switch ON? Står der "Pump disabled" i log?
3. **Tjek 12V skinne**: mål med multimeter ved pumpe-terminaler når GPIO er HIGH. Skal være 12V ±0.5V.
4. **Tjek MOSFET-gate**: GPIO PWM skal være HIGH (3.3V). Hvis 0V: software-bug i `pump.cpp`.
5. **Tjek slange**: er der knæk på slangen? Er pumpe-rotoren blokeret?

## HomeKit viser ikke device

1. **Thread Border Router aktiv?**: HomePod mini / Apple TV 4K / iPad Pro M-serie. Tjek i Home-app → Settings → "Thread Network".
2. **Distance til border router**: ESP32-C6 Thread radio rækker ~10m gennem vægge. Flyt tættere ved første pairing.
3. **Reset device**: hold manuel-knap nede i 10 sek ved boot → factory reset, åbner pairing-mode igen.
4. **Tjek log**: serial monitor skal vise `Matter device ready, QR code: ...`. Hvis ingen QR: ESP-Matter SDK init fejler.

## Soil moisture læser konstant 0% eller 100%

1. **0%**: Sensoren rører ikke jord. Sæt den længere ned i jorden (men ikke så langt at elektronikken rører jord).
2. **100%**: Sensoren rører jord-overfladen og er måske over-vandet, eller sensoren har vand-skade. Verificer i tør luft først.
3. **Stuck**: re-kalibrer (se [calibration.md](calibration.md) sektion 2).
4. **Korrosion**: hvis sensor-pad er begyndt at korrodere → udskift sensor. Brug ALDRIG resistive sensorer — kun kapacitive.

## Vægt-aflæsning drifter

1. **Temperatur-skift**: HX711 har ~50 ppm/°C drift. Hvis værelse-temperatur ændres betydeligt → re-tare via HomeKit-knap.
2. **Termisk drift fra egen elektronik**: ESP32 + buck-converter genererer ~1-2W der vandrer ned gennem electronics base i load cell. Drift på ~0.5g/°C ved 5kg cell. **Mitigation**: indsæt 2-3mm rubber-pad mellem `electronics_base_lid` og `load_cell_mount` upper plate.
3. **Krukke flyttet**: load cell er sensitiv overfor placering. Hvis krukken er flyttet → re-tare.
4. **Cable issue**: tjek at load cell wires ikke er løse i HX711-modulet.

## Vægt-aflæsning er støjende, især under/efter pumpning

Pumpen sidder i electronics base, direkte over load cell. Mekaniske vibrationer forplanter sig ind i cellen.

1. **Verificer firmware filtrerer korrekt**: 5-sample moving average skal være aktivt. Tjek `weight_filter()` i sensors.cpp.
2. **Sample timing**: firmware MÅ ikke læse HX711 mens `pump_active = true`. Verificer i log at sample-timestamps ikke ligger inden for pumpe-cyklus.
3. **Vent-tid efter pump stop**: minimum 30 sek før første nye gyldige sample. Mekaniske oscillationer dør først ud da.
4. **Vibration fra eksterne kilder**: vaskemaskine, gulv-stomp, etc. Moving average filtrerer 1-2 sek spikes. Hvis vedvarende støj — flyt krukken eller læg blød mat under.

## Vandlækage til elektronik

**Stop alt med det samme**. Tag USB-C ud.

1. Tag electronics base af.
2. Tør komplet med absorbing klud + 24t i tørt rum.
3. Inspicer for korrosion på pin headers og passive komponenter.
4. Find lækage-kilde: typisk slange-grommet eller PG7 cable gland. Skift gasket.
5. Test electronics base separat (uden vand) før samling igen.

**Forebyggelse**: drænhullet i electronics base bund skal være åbent (papir-clip kan rense det).

## Krukken vibrerer / udsender støj

1. **Pumpe mekanisk klik**: normalt for peristaltisk pumpe. Acceptabelt ved 100 sek/dag drift.
2. **Vibration fra electronics base**: monteringen er løs. Spænd M3-bolte.
3. **Whining / pibe-lyd**: buck-converter switching noise. Forsøg at flytte MP1584 længere væk fra MCU og pumpe-loop. Tilføj 100µF elko ved input/output.

## Firmware bygger ikke

1. **`platformio.ini` framework-mismatch**: Skal være `framework = espidf`, ikke `arduino`. ESP-Matter SDK kræver IDF.
2. **esp-matter component fail**: kør `pio pkg update` og tjek at `dependencies.lock` ikke er gammel.
3. **Out of memory under link**: ESP-Matter er stor. Tjek at partition table giver mindst 2MB til app.
4. **Toolchain mismatch**: platform `espressif32 @ ^6.5.0` matcher med ESP-IDF 5.1+. Hvis du ser GCC-fejl: pin til specifik version.

## Plante ser tør ud trods systemet vander

1. **Profile mismatch**: tjek at aktiv profil matcher plantetypen. Succulent-profil på Monstera → kraftig under-vanding.
2. **Cooldown for lang**: `cooldown_min` for høj → planten kan tørre ud mellem doseringer. Sænk til 50% af nuværende.
3. **Dose for lille**: `dose_ml` for lille → vandet når ikke rødderne. Hæv til 50% mere.
4. **Drip-ring tilstoppet**: små huller kalker til over tid. Rens med en safety pin.

## Plante ser over-vandet ud (gulnende blade, råd)

1. **Profile for våd**: succulent-profil bør have `target_max_pct` ≤ 20%. Tjek aktuel profil.
2. **`daily_ml_cap` for høj**: hvis pumpen kører for ofte → safety-cap stopper det. Sænk daily cap.
3. **Drænage problem**: dræn-huller i plant cup tilstoppet → vand står i bund. Tjek + rens.

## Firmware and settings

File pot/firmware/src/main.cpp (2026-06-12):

/**
 * @file main.cpp
 * @brief GreenThumbs Plantekrukke — entry point + FreeRTOS task setup.
 *
 * Arkitektur (se docs/architecture.md):
 *   - sensor_task: sampler soil/water/weight hver 30s
 *   - control_task: evaluerer profil, beslutter om pumpe skal trigges
 *   - matter_task: Matter event loop + cluster updates
 *   - safety_task: watchdog, float-switch ISR håndtering, leak detection
 *
 * Shared state mellem tasks beskyttes med FreeRTOS mutexes.
 *
 * STATUS: skeleton. Fyldes ud i Fase 1 (firmware bring-up).
 */

// Hele filen er ESP-IDF-specifik — udelukkes fra native unit-test builds
// (test/native/ bygger src/ via test_build_src; kun pure-math filer skal med).
#ifndef NATIVE_TEST

#include <stdio.h>
#include "freertos/FreeRTOS.h"
#include "freertos/task.h"
#include "freertos/semphr.h"
#include "esp_log.h"
#include "nvs_flash.h"

#include "profiles.h"
#include "temp_humidity.h"
#include "buzzer.h"

static const char *TAG = "greenthumbs";


// =============================================================================
// Pin assignments — se pot/hardware/breadboard/wiring-diagram.md
// =============================================================================
// NB: D4/D5 er nu reserveret til AHT20 I2C (SDA/SCL). HX711 er flyttet til
// D6/D7. ESP-IDF console kører på USB-CDC i stedet for UART (se ADR 007).
constexpr int PIN_SOIL_ADC      = 0;   // D0 / GPIO0 / ADC1_CH0
constexpr int PIN_WATER_ADC     = 1;   // D1 / GPIO1 / ADC1_CH1
constexpr int PIN_BUZZER        = 2;   // D2 / GPIO2 (piezo buzzer, LEDC PWM)
constexpr int PIN_FLOAT_SWITCH  = 21;  // D3 / GPIO21
constexpr int PIN_I2C_SDA       = 22;  // D4 / GPIO22 (AHT20)
constexpr int PIN_I2C_SCL       = 23;  // D5 / GPIO23 (AHT20)
constexpr int PIN_HX711_SCK     = 16;  // D6 / GPIO16
constexpr int PIN_HX711_DOUT    = 17;  // D7 / GPIO17
constexpr int PIN_STATUS_LED    = 19;  // D8 / GPIO19 (WS2812)
constexpr int PIN_MANUAL_BUTTON = 20;  // D9 / GPIO20
constexpr int PIN_PUMP_GATE     = 18;  // D10 / GPIO18 (MOSFET PWM)


// =============================================================================
// Shared state
// =============================================================================
struct sensor_state_t {
    uint8_t moisture_pct;
    uint8_t water_level_pct;
    bool float_low;          // true hvis float-switch siger vand tom
    int32_t weight_g;
    float temp_c;            // fra AHT20
    float humidity_pct;      // fra AHT20
    float vpd_kpa;           // beregnet VPD
    uint32_t last_update_ms;
};

struct pump_state_t {
    uint32_t last_pump_ms;
    uint16_t daily_ml;
    uint32_t day_start_ms;   // til at resette daily_ml ved midnat
};

static sensor_state_t g_sensors;
static pump_state_t g_pump;
static plant_profile_t g_active_profile;
static SemaphoreHandle_t g_state_mutex;


// =============================================================================
// Task forward declarations
// =============================================================================
static void sensor_task(void *pvParameters);
static void control_task(void *pvParameters);
static void matter_task(void *pvParameters);
static void safety_task(void *pvParameters);


// =============================================================================
// Setup helpers
// =============================================================================
static esp_err_t init_nvs(void)
{
    esp_err_t err = nvs_flash_init();
    if (err == ESP_ERR_NVS_NO_FREE_PAGES || err == ESP_ERR_NVS_NEW_VERSION_FOUND) {
        ESP_ERROR_CHECK(nvs_flash_erase());
        err = nvs_flash_init();
    }
    return err;
}

static void init_pins(void)
{
    // TODO: gpio_config for alle pins
    // ADC1 init for soil og water pins
    // Pull-up på float switch og button
    // PWM init for pump gate
    // RMT init for WS2812 LED
    ESP_LOGI(TAG, "Pin init: TODO (Fase 1)");
}

static void init_matter(void)
{
    // TODO: ESP-Matter SDK initialisering
    //   1. esp_matter::node_t create
    //   2. Tilføj endpoints: humidity sensor (soil), humidity sensor (water),
    //      leak detector (float), on/off switch (manual pump), mode select (profile)
    //   3. esp_matter::start()
    //   4. Print QR-code til serial for first-time pairing
    ESP_LOGI(TAG, "Matter init: TODO (Fase 1)");
}


// =============================================================================
// Entry point
// =============================================================================
extern "C" void app_main(void)
{
    ESP_LOGI(TAG, "=== GreenThumbs Plantekrukke booting (v%s) ===", GREENTHUMBS_VERSION);

    // 1. NVS init
    ESP_ERROR_CHECK(init_nvs());

    // 2. Load aktiv profil (eller default = Monstera)
    if (profile_load_from_nvs(&g_active_profile) != 0) {
        ESP_LOGW(TAG, "No saved profile, using default: %s",
                 PROFILE_DEFAULTS[PROFILE_MONSTERA].name);
        g_active_profile = PROFILE_DEFAULTS[PROFILE_MONSTERA];
    }
    ESP_LOGI(TAG, "Active profile: %s", g_active_profile.name);

    // 3. State mutex
    g_state_mutex = xSemaphoreCreateMutex();

    // 4. Hardware init
    init_pins();

    // 5. Environmental sensor (AHT20 over I2C)
    if (env_sensor_init() != 0) {
        ESP_LOGW(TAG, "AHT20 init failed — VPD-aware dosing disabled");
        // Fortsætter med graceful degradation (se ADR 007)
    }

    // 6. Matter stack
    init_matter();

    // 7. Spawn tasks
    // Stack sizes (audit-fix): Matter event-handling + I2C/ADC-buffere kræver
    // mere end de oprindelige gæt. TODO Fase 1: mål reelt forbrug med
    // uxTaskGetStackHighWaterMark() og trim.
    xTaskCreate(sensor_task,  "sensor",  8192,  nullptr, 5, nullptr);
    xTaskCreate(control_task, "control", 4096,  nullptr, 5, nullptr);
    xTaskCreate(matter_task,  "matter",  16384, nullptr, 4, nullptr);
    xTaskCreate(safety_task,  "safety",  2048,  nullptr, 6, nullptr);

    ESP_LOGI(TAG, "All tasks started, app_main exiting.");
}


// =============================================================================
// Task implementations (skeletons)
// =============================================================================

static void sensor_task(void * /*pvParameters*/)
{
    const TickType_t period = pdMS_TO_TICKS(30 * 1000);
    TickType_t last_wake = xTaskGetTickCount();

    for (;;) {
        // TODO Fase 1:
        //   - Læs soil ADC, beregn moisture_pct via profile_moisture_pct()
        //   - Læs water level ADC, beregn pct
        //   - Læs float switch
        //   - Læs HX711 (DETECT_WEIGHT/HYBRID modes, hvis available)
        //   - Læs AHT20 hver 60s (env_sensor_read), beregn VPD
        //   - Lås mutex, opdater g_sensors (inkl. temp/humidity/vpd), frigør mutex
        //   - REFILL-DETECTION (ADR 008): hvis water level steg >5 procentpoint
        //     på 10 sek → refill-mode → buzzer_pattern(BUZZ_REFILL_PROGRESS)
        //     ved 25/50/75% og BUZZ_REFILL_FULL ved ≥95%. Forlad mode efter
        //     30 sek stabil level.
        //
        // VIGTIGT: spring HX711-sample over hvis pump_active = true (vibrationer
        // forplanter sig fra pump til load cell). Se docs/architecture.md.

        ESP_LOGD(TAG, "[sensor] sample tick");
        vTaskDelayUntil(&last_wake, period);
    }
}

static void control_task(void * /*pvParameters*/)
{
    const TickType_t period = pdMS_TO_TICKS(60 * 1000);
    TickType_t last_wake = xTaskGetTickCount();

    for (;;) {
        // TODO Fase 1:
        //   - Lås mutex, kopier g_sensors + g_pump + g_active_profile
        //   - Frigør mutex
        //   - Kald profile_should_pump(...)
        //   - Hvis true:
        //       * dose = profile_effective_dose_ml(&profile,
        //                    g_sensors.vpd_kpa, env_sensor_available())
        //       * Trig pumpe via pump_dose_ml(dose)
        //   - Opdater g_pump.last_pump_ms og daily_ml

        ESP_LOGD(TAG, "[control] eval tick");
        vTaskDelayUntil(&last_wake, period);
    }
}

static void matter_task(void * /*pvParameters*/)
{
    // ESP-Matter har sin egen event loop. Denne task wrapper det
    // og synker cluster-værdier til vores g_sensors-state.
    for (;;) {
        // TODO Fase 1:
        //   - Hver 10s: lås mutex, læs g_sensors, opdater Matter cluster-attributter
        //   - Håndter incoming commands (manual pump trigger, profile change)
        vTaskDelay(pdMS_TO_TICKS(10 * 1000));
    }
}

static void safety_task(void * /*pvParameters*/)
{
    for (;;) {
        // TODO Fase 1:
        //   - Tjek at sensor_task ikke er stuck (g_sensors.last_update_ms ny nok)
        //   - Tjek float-switch ISR-counter
        //   - Hvis vægt falder hurtigere end forventet → leak suspected → disable pump
        //   - Watchdog feed
        vTaskDelay(pdMS_TO_TICKS(5 * 1000));
    }
}

#endif  // !NATIVE_TEST

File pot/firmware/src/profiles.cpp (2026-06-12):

/**
 * @file profiles.cpp
 * @brief Planteprofiler — factory defaults + beslutningslogik.
 *
 * Threshold-logik og dose-beregning er fuldt implementeret (pure functions,
 * native-testbare). NVS-persistens er stub indtil Fase 1.
 *
 * Profil-værdier dokumenteret i docs/plant-profiles.md — ret dem DÉR først,
 * og synk derefter hertil.
 */

#include "profiles.h"
#include "temp_humidity.h"

#include <string.h>

// =============================================================================
// Factory defaults — se docs/plant-profiles.md for begrundelser
// =============================================================================
// adc_dry/adc_wet er typiske startværdier (DFRobot capacitive v2 @ 3.3V);
// overskrives af reel kalibrering per sensor (docs/calibration.md).
//
// Felt-rækkefølge: name, mode, adc_dry, adc_wet, target_min, target_max,
//                  weight_baseline_g, weight_dry_delta_g,
//                  dose_ml, cooldown_min, daily_ml_cap,
//                  soak_seconds, soak_repeats, soak_pause_seconds

const plant_profile_t PROFILE_DEFAULTS[PROFILE_COUNT] = {
    // PROFILE_MONSTERA — tropisk, moisture-styret, top-drip
    { "monstera",       DETECT_MOISTURE, 3000, 1200, 35, 55,
      0, 0,
      50, 360, 100,
      0, 0, 0 },

    // PROFILE_POTHOS — tørke-tolerant tropisk
    { "pothos",         DETECT_MOISTURE, 3000, 1200, 30, 50,
      0, 0,
      30, 720, 60,
      0, 0, 0 },

    // PROFILE_PEACE_LILY — fugt-elsker, wick anbefales
    { "peace_lily",     DETECT_MOISTURE, 3000, 1200, 40, 60,
      0, 0,
      40, 480, 100,
      0, 0, 0 },

    // PROFILE_AFRICAN_VIOLET — wick-ONLY: dose 0, pumpe aldrig aktiv
    { "african_violet", DETECT_MOISTURE, 3000, 1200, 35, 50,
      0, 0,
      0, 0, 0,
      0, 0, 0 },

    // PROFILE_SUCCULENT — minimal vanding, lange tørre perioder, INGEN wick
    { "succulent",      DETECT_MOISTURE, 3000, 1200, 10, 20,
      0, 0,
      15, 4320, 15,
      0, 0, 0 },

    // PROFILE_ORCHID — vægt-styret soak-cyklus (kræver HX711, ADR 004)
    { "orchid_phal",    DETECT_WEIGHT,   0, 0, 0, 0,
      0, -80,
      0, 10080, 100,
      10, 3, 30 },

    // PROFILE_CUSTOM — konservative defaults, alt bruger-redigerbart
    { "custom",         DETECT_MOISTURE, 3000, 1200, 25, 45,
      0, 0,
      25, 720, 50,
      0, 0, 0 },
};


// =============================================================================
// NVS-persistens — stub indtil Fase 1 (kræver ESP-IDF nvs_flash API)
// =============================================================================

int profile_load_from_nvs(plant_profile_t *profile)
{
    // TODO Fase 1: nvs_open("greenthumbs") → nvs_get_blob("profile")
    // Returnér -1 så main.cpp falder tilbage på PROFILE_DEFAULTS[MONSTERA].
    (void)profile;
    return -1;
}

int profile_save_to_nvs(const plant_profile_t *profile)
{
    // TODO Fase 1: nvs_set_blob + nvs_commit
    (void)profile;
    return -1;
}


// =============================================================================
// Beslutningslogik — pure functions, native-testbare
// =============================================================================

uint8_t profile_moisture_pct(uint16_t adc_reading, const plant_profile_t *profile)
{
    // Kapacitiv sensor: højere ADC = tørrere. pct = 100*(dry-x)/(dry-wet)
    if (profile == NULL || profile->adc_dry <= profile->adc_wet) {
        return 0;  // ukalibreret eller defekt config — rapportér tørt (fail-safe
                   // mod over-vanding sker via cooldown + daily cap, ikke her)
    }

    if (adc_reading >= profile->adc_dry) return 0;
    if (adc_reading <= profile->adc_wet) return 100;

    uint32_t span = (uint32_t)(profile->adc_dry - profile->adc_wet);
    uint32_t above_wet = (uint32_t)(profile->adc_dry - adc_reading);
    return (uint8_t)(100u * above_wet / span);
}

bool profile_should_pump(uint8_t moisture_pct,
                          int32_t weight_g,
                          uint32_t last_pump_minutes_ago,
                          uint16_t daily_ml_so_far,
                          const plant_profile_t *profile)
{
    if (profile == NULL) return false;

    // Wick-only profiler (dose 0) pumper aldrig
    if (profile->dose_ml == 0 && profile->mode == DETECT_MOISTURE) {
        // orchid har også dose_ml = 0 men bruger soak_seconds — undtag WEIGHT-mode
        return false;
    }

    // Safety: cooldown mellem doseringer
    if (last_pump_minutes_ago < profile->cooldown_min) return false;

    // Safety: dagligt loft
    if (profile->daily_ml_cap > 0 && daily_ml_so_far >= profile->daily_ml_cap) {
        return false;
    }

    bool moisture_dry = (moisture_pct < profile->target_min_pct);
    bool weight_dry =
        (weight_g <= profile->weight_baseline_g + profile->weight_dry_delta_g);
    // weight_dry_delta_g er negativ: baseline 1200 + (-80) = trigger ved <= 1120g

    switch (profile->mode) {
    case DETECT_MOISTURE:
        return moisture_dry;
    case DETECT_WEIGHT:
        return weight_dry;
    case DETECT_HYBRID:
        return moisture_dry && weight_dry;
    default:
        return false;
    }
}

uint16_t profile_effective_dose_ml(const plant_profile_t *profile,
                                    float vpd_kpa,
                                    bool env_available)
{
    if (profile == NULL) return 0;
    if (!env_available) return profile->dose_ml;  // graceful degradation

    float scaled = (float)profile->dose_ml * env_vpd_dose_scale(vpd_kpa);
    return (uint16_t)(scaled + 0.5f);
}

bool profile_validate(const plant_profile_t *profile, bool weight_available)
{
    if (profile == NULL) return false;

    if ((profile->mode == DETECT_WEIGHT || profile->mode == DETECT_HYBRID)
        && !weight_available) {
        return false;  // profil kræver load cell der ikke er installeret (ADR 004)
    }
    return true;
}

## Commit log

2026-05-27 Scaffold project: docs, ADRs, firmware skeleton, BOM, tower notes
    Initial scaffolding for the GreenThumbs two-design auto-watering
    project (plantekrukke v1 + væg-tower v2):
    - Root: README, MIT LICENSE, .gitignore, .editorconfig
    - docs/: architecture, plant-profiles (6 profiles), calibration,
    troubleshooting
    - docs/decisions/: 5 ADRs covering peristaltic pump, XIAO ESP32-C6,
    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
    [bom.csv, params.scad, partitions.csv]
2026-05-27 feat: optional load cell hardware + CAD source for all 4 parts
    Hardware/strategy:
    - BOM: upgrade load cell to 5kg (was 1kg); mark HX711+cell as OPTIONAL
    - ADR 004: refined strategy — weight detection only needed for orchid
    (bark medium); jord-baserede planter inkl. succulenter klarer sig med
    moisture sensor alene. Større planter (Monstera) bygges helt uden
    load cell.
    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
    [bom.csv, electronics_base.scad, load_cell_mount.scad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]
2026-05-27 fix(cad): load cell mount cantilever — bosser ved bolt-punkter
    Tidligere design klampede hele cellen mellem to flade plader. En bar
    strain gauge load cell måler ved at BØJE under belastning — hvis begge
    ender er fastgjort fladt, kan cellen ikke bøje og strain gauges læser
    ~0 uanset vægt. Det er en klassisk mounting-fejl.
    Korrekt cantilever-mount:
    - Lower plate boss kontakter KUN cellens fixed end (fra under)
    - Upper plate boss kontakter KUN cellens free end (fra over)
    - Cellens midte + det modsatte end er i AIR (~4mm gap)
    Implementation:
    - params.scad: tilføj boss_height/boss_l/boss_w + loadcell_fixed_x/free_x
    - load_cell_mount.scad: omskrevet med plate_with_boss() der cent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
    [load_cell_mount.scad, params.scad]
2026-05-28 docs: load cell placement rationale + pump/thermal mitigation notes
    architecture.md:
    - New section "Load cell-placering: bivirkninger" explaining why the
    load cell sits at the bottom of the stack (water tubing constraint,
    HX711 wiring length, mechanical stability) and the resulting trade-
    offs.
    - Documents two side-effects with mitigation:
    - Pump vibrations propagating into load cell → firmware skip during
    pump-active + 30s settle time + 5-sample moving average
    - Thermal drift from electronics → rubber pad isolator + periodic
    re-tare
    troubleshooting.md:
    - Extended "Vægt-aflæsning drifter" with thermal-drift case + rubber
    pad mitigation
    - New section "Vægt-aflæsni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
2026-05-28 feat: wick bottom-watering (v1) + pot-orchid v2 planning track
    Add wick capability for v1 + create dedicated pot-orchid/ design track:
    ADR 006:
    - Document bottom-watering strategy: wick now (v1), soak-tray later (v2)
    - Wick = cotton/nylon cord through existing center drain hole (no CAD
    changes needed for v1)
    - Soak-tray deferred to dedicated pot-orchid/ variant
    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
    [bom.csv]
2026-05-28 feat: AHT20 environmental sensor som standard v1-komponent (VPD-aware)
    Tilføj AHT20 temp+humidity sensor som STANDARD v1-komponent (ikke
    optional som load cell). Soil sensor er reaktiv; AHT20 muliggør
    predictive vanding og VPD-baseret dose-skalering.
    Pin-rearrangement:
    - D4/D5 (var HX711) → AHT20 I2C SDA/SCL (default I2C pins)
    - D6/D7 (var UART) → HX711 SCK/DOUT
    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
    [bom.csv]
2026-06-12 docs+feat: piezo/KiCad research, refill buzzer (ADR 008), buzzer skeleton
    Research (docs/research/, ny mappe):
    - kicad-round-pcb.md: rund PCB er native KiCad (Edge.Cuts cirkel);
    DXF-flow fra OpenSCAD projection() sikrer PCB matcher electronics_base;
    circuit-synth som kode-defineret workflow-kandidat; JLCPCB uden merpris
    - piezo-components.md: Bartels BP7 piezo-pumpe (~925 DKK m. driver)
    FRAVALGT i v1 — pumpe-energi er allerede negligibel (0.1 af ~2.5 Wh/dag),
    støj-gevinst marginal ved 100 sek drift/dag. Dual-footprint pump-mount
    planlagt så BP7 kan eftermonteres. Piezo buzzer VALGT til refill.
    Energy harvesting afvist (µW-niveau).
    ADR 008 — Refill-indikator:
    - Passiv piez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
    [bom.csv]
2026-06-12 fix(firmware): partition table 4MB, IDF 5.2+, profiles.cpp + 9 native tests
    Audit-fixes fra firmware-gennemgang (alle 3 kritiske fund løst):
    KRITISK — partitions.csv kunne ikke flashes (6MB layout på 4MB chip):
    - Var: factory + 2×OTA á 1984KB → sluttede ved 0x600000 (6MB)
    - Nu: factory + 1 OTA á 1792KB + 448KB storage → præcis 0x400000 (4MB)
    - Aritmetik dokumenteret i fil-kommentar; OTA-flow er A/B-swap
    KRITISK — driver/i2c_master.h fandtes ikke i IDF 5.1:
    - platform hævet espressif32 ^6.5.0 → ^6.9.0 (IDF 5.2+ til ny I2C API)
    - Verifikations-note + pioarduino-fallback dokumenteret i platformio.ini
    KRITISK — PROFILE_DEFAULTS extern uden definition (linker-fejl):
    - profil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
    [partitions.csv]
2026-06-12 fix(cad): ebase bosses overlevede ikke cavity-cut + port-align + dual pump-mount
    Audit-fixes fra CAD-gennemgang:
    KRITISK — mounting bosses blev ædt af cavity-subtraktion:
    - electronics_base() havde bosses i samme union som shell FØR cavity
    blev subtraheret → cavity-cylinderen (r=90) åd bosserne (r 81.5-90.5)
    så kun 0.5mm flager bestod. M3-inserts havde intet at sidde i.
    - Fix: restruktureret til shell-difference først, bosses unions bagefter,
    insert-huller subtraheres til sidst.
    - VERIFICERET: render nedefra viser 4 intakte bosses med insert-huller.
    MODERAT — pump-port offset 1.5mm:
    - Reservoir-port (inner_d/4=45) og ebase-port (outer_d/4=46.5) flugtede
    ikke. Ny fælles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
    [electronics_base.scad, params.scad, reservoir.scad]
2026-06-12 feat(cad): stack-variant A/B preview til geometri-beslutning
    stack_variants_preview.scad: side-om-side halv-snit af de to mulige
    redesigns af cup/reservoir-geometrien (audit fandt nuværende umulig):
    - Variant A (venstre): cup hænger nedsænket i højt reservoir (~196mm).
    Klassisk self-watering. Vand-zone 40mm under cup, wick kort vej,
    ~1000 ml kapacitet, fugtigt mikroklima om cup. Cup drypper ved løft.
    - Variant B (højre): cup står ovenpå lavt lukket reservoir (58mm) med
    dræn-rist + wick-gennemføring. Reservoir-print lille, cup løftes
    tørt af. Wick-afstand 30-55mm (svagere), 700 ml.
    pot/cad/preview/stack-variants-AB.png: renderet beslutningsgrundlag.
    Ikke print-geometri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
    [stack_variants_preview.scad]
2026-06-12 feat(cad): implementér stack variant A — cup nedsænket i højt reservoir
    Variant A valgt af bruger efter A/B-preview (klassisk self-watering).
    Geometrien er nu fysisk konsistent — audit-fundets umulige stack
    (160mm cup i 57mm reservoir) er løst.
    params.scad:
    - reservoir_height er nu OUTPUT af cup-geometri: (cup_height -
    top_ring_height) + water_zone_h(40) + wall. Volumen-INPUT fjernet;
    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
    [assembly_check.scad, params.scad, plant_cup.scad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]
2026-07-12 feat(cad): overflow + zero-penetration reservoir (ADR 009) + preview-sæt
    Baggrund: bruger spottede at nedsænket cup med drænhuller kan vandfyldes
    ved overfyldning (rodforrådnelse). Gen-inspektion afslørede yderligere tre
    lækage-problemer: strip-slot skar gennem væggen, pump-port var åbent hul i
    bunden, og sensor-kabler havde ingen designet rute.
    ADR 009 — Zero-penetration + overflow:
    - Reservoiret har nu INGEN gennemføringer under vandlinjen (bund + væg
    er én tæt print). Alle slanger/kabler ruter: ring-gab → flange-åbninger
    → udvendigt → ebase side-glands
    - Overflow-hul Ø5 ved 270°, 8mm under cup-bund — fysisk umuligt at
    overfylde; overløb drypper synligt i p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
    [assembly_check.scad, bom.csv, electronics_base.scad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]
2026-07-14 feat(cad): adaptiv diameter — fast ring_gap, matchende sæt, CUSTOM størrelse
    Bruger-feedback: one-size reservoir gav svingende ring-gab (10-40mm),
    spildplads i pyntepotten, og risiko for skævt-siddende cup. Redesignet:
    Adaptiv diameter:
    - ring_gap = 20mm FAST konstant (dimensionerer slanger/strip/kabler/refill)
    - reservoir_inner_d = cup_diameter + 2*ring_gap → hele kæden (reservoir,
    ebase, lid, load cell platform) skalerer automatisk (var allerede
    parametrisk afledt — kun rod-linjen ændret)
    - L-cup tilbage til Ø180 (gap er nu garanteret uanset størrelse)
    - Trade-off dokumenteret: hver størrelse er nu et MATCHENDE SÆT
    (reservoir+base re-printes per størrelse; cups kan i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
    [assembly_check.scad, params.scad, plant_cup.scad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]
2026-07-14 feat(cad): scalloped cup med service-kanaler (ADR 010) — brugerens design
    Bruger-forslag: drop kravet om cirkulær cup. I stedet for et koncentrisk
    ring-gab (der ofrede ~40% af det indre tværsnit til mest tom luft) fylder
    cuppen nu næsten hele reservoir-åbningen (1mm kant-clearance) med 3
    lodrette SERVICE-KANALER skåret konkavt i kanten:
    - 90° KABEL-KANAL Ø16: soil/strip/float-kabler
    - 180° SLANGE-KANAL Ø18: suge+tryk; dyse-hul i kanal-flade nær cup-top
    - 270° REFILL-KANAL Ø28: påfyldning + water-strip m. guide-ribber
    Orientering GRATIS via geometrien (brugerens pointe): strip-ribberne på
    reservoir-væggen (nu fuld højde) spænder ~26mm og passerer KUN den brede
    refill-ka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
    [params.scad, plant_cup.scad, reservoir.scad]
2026-10-21 fix(bom): forkerte parts rettet + manglende dele tilføjet til nuværende design
    Fejl-parts (verificeret mod forhandler-data):
    - Pos 8: DFRobot SEN0204 er en BINÆR berøringsfri switch (XKC-Y25), ikke
    en gradueret strip — refill-buzzer og HomeKit-vandstand forudsætter
    gradueret aflæsning. Erstattet af Seeed Grove Water Level Sensor 10cm
    (101020635): kapacitiv, belagt, I2C 0x77/0x78, 20x133mm, ±5mm.
    Deler I2C-bus med AHT20 → D1 frigjort som reserve.
    - Pos 1: XIAO ESP32-C6 SKU 113991138 → 113991254
    - Pos 2: "Kamoer KPP" findes ikke → Kamoer KXF-DC-S06 (12V 0.25A
    ~37 ml/min); 46mm flange-hulafstand i CAD markeret som ANTAGELSE
    - Pos 11: TAL220(B) 5kg er 55mm/M5 og passer i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
2026-10-21 feat(orchid): design v0 — to-kammer flood-and-drain med vendbar pumpe (ADR 011)
    Første design-iteration af orkide-versionen. Planlægningsnoterne fra maj/juni
    (soak-tray + magnetventil/passivt overløb + piezo-pumpe) var skrevet før
    ADR 009/010 og er erstattet.
    Koncept (brugervalg: vendbar peristaltisk pumpe, ~260 ml/min, 12cm
    Phalaenopsis, klar cup):
    - Klar orkide-cup (scalloped, bund-huller + side-slidser) hænger i klart
    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
2026-10-21 feat(orchid): v1 — dyrkningspotte i konisk skål, lager-ring, batteri (ADR 012/013)
    Orkide v1 (ADR 012, erstatter v0-geometrien i ADR 011):
    - Ø180 tårn der passer i pyntepotten: konisk skål til 12cm dyrkningspotte,
    lager-ring rundt om (~900 ml), bay til elektronik + batteri i bunden
    - Skålens kant er soak-loft (68mm, ~376 ml) — mekanisk, ikke firmware
    - Kamoer NKP + DRV8871 (vendbar), XKC berøringsfri "skål tom", 2 floats
    - Trigger: interval + VPD; ingen load cell, Grove eller soil-sensor
    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
2026-10-21 fix(firmware): første ESP32-C6-build — 4MB flash + OpenThread-workaround
    - Flash sat til 4MB (XIAO) i platformio.ini og sdkconfig.defaults:
    board-filen sagde 8MB og sdkconfig 2MB, mens partitions.csv kræver 4MB
    - scripts/fix_ot_datetime.py: PlatformIO's espidf-builder citerer
    OPENTHREAD_BUILD_DATETIME (mellemrum) forkert → OpenThread kompilerede ikke
    - CMakeLists.txt (genereret af PlatformIO) committet; sdkconfig.<env> ignoreres
    - README: PlatformIO kræver Python ≤ 3.13 (ESP-IDF 5.5-deps fejler på 3.14)
    Verificeret: espressif32 6.13.0 / ESP-IDF 5.5.3 bygger (RAM 3.2%, flash
    8.7% af app-slot); 9/9 native tests består.
2026-10-21 feat(cad): plads til ladning — USB-C ved kanten + Qi i bunden (ADR 013)
    Orkide:
    - Egen tør USB-C-skakt ved 60° op gennem ring-låget (hun-enden flugter
    med låget); et stik under låget ville nå vandet. Lager nu ~880 ml
    - Qi-lomme midt i bay-gulvet (1,2mm gulv); batterivuggen flyttet ud
    (cradle_y 52) → ~14mm fra spole til celler
    pot/:
    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
2026-10-21 feat(power): TP4056 ved 580 mA + OTA-partitioner der rent faktisk virker
    Ladning (ADR 013):
    - TP4056 USB-C-modul m. DW01-beskyttelse erstatter pos 37; R_PROG byttes
    til 2,0kΩ (ny pos 47) → 580 mA, ~12-14 t i stedet for ~3 døgn
    - USB-C-forlængeren og Qi-dioden går til modulet; alle forbrugere på
    OUT+/OUT-. USB-C ved kanten lader kun — firmware via Matter OTA
    OTA (fix):
    - partitions.csv havde factory + ota_0 og ingen otadata → OTA kunne ikke
    køre (ESP-IDF kræver ≥2 OTA-slots + otadata). Nu ota_0/ota_1 à 1920 KB,
    nvs 128 KB til Matter, storage 64 KB
    - CONFIG_BOOTLOADER_APP_ROLLBACK_ENABLE=y
    Verificeret: bygger (ESP-IDF 5.5.3), partitionstabel dumpet og korrekt.
    Co-Aut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
2026-10-21 feat(orchid): ladebase til Apple MagSafe 25W (ADR 013)
    - charging_base.scad: Ø189 × 15mm, konisk sæde til bay'ens 45°-fas
    (±0,5mm centrering), lomme til MagSafe (Ø55,5 × 4,45mm, A2580) der
    stikker 0,1mm op, så tårnet hviler direkte på laderen
    - Udskubningshul under laderen, kabel-kanal radialt ud (åben nedad under
    kanten), alle synlige kanter afrundet (r 2,2), 45° fas forneden
    - Nye views i assembly.scad: "base" og "charging"; snit-kuben gjort
    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
2026-10-21 feat(bom): brug DTU-komponentshoppen til passive + diskrete dele
    Afvejning i docs/research/dtu-component-shop.md. Indført 1:1:
    - 1N5817 erstatter 1N5819 (lavere Vf til Qi-OR-ing, 20V nok til flyback)
    - BS170 (TO-92) erstatter 2N7002 som gate-driver — ingen SOT-23-adapter
    - Modstande (10k/100k/200k + 4,75k/5,11k fallbacks), elkoer/keramiske og
    knap fra DTU; nye pos 48-49: skrueterminaler + female headers til
    stripboard-prototypen
    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
2026-10-26 feat: skift MCU til ESP32-H2 (ADR 014) — pins, BOM, PlatformIO, indkøbsliste
    - ADR 014: ESP32-H2 i stedet for C6 — 802.15.4 RX 25 vs 74 mA, TX 36 vs
    119 mA, light-sleep 25/85 vs 35/180 µA (datablade). OTA uændret (Matter
    OTA over Thread, 4MB/H4S). ADR 002 markeret superseded
    - Prototype: Waveshare ESP32-H2-Zero; færdigt PCB: ESP32-H2-MINI-1-H4S
    - Nye pins (ens på Zero og modul): de 11 rene GPIO 0-5, 10-12, 22, 23;
    fælles buzzer 0, batteri 3, I2C 4/5, knap 12 (LP-pin), boost 22.
    Fri: 8/9/25 (strapping), 24 (ROM-log), 13/14 (32 kHz), 26/27 (USB)
    - Batteri via 1N5817 til Zero'ens 5V-pin (ingen USB-backfeed i cellerne)
    - PlatformIO: pioarduino 55.03.312-1 (officiel platform kan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
